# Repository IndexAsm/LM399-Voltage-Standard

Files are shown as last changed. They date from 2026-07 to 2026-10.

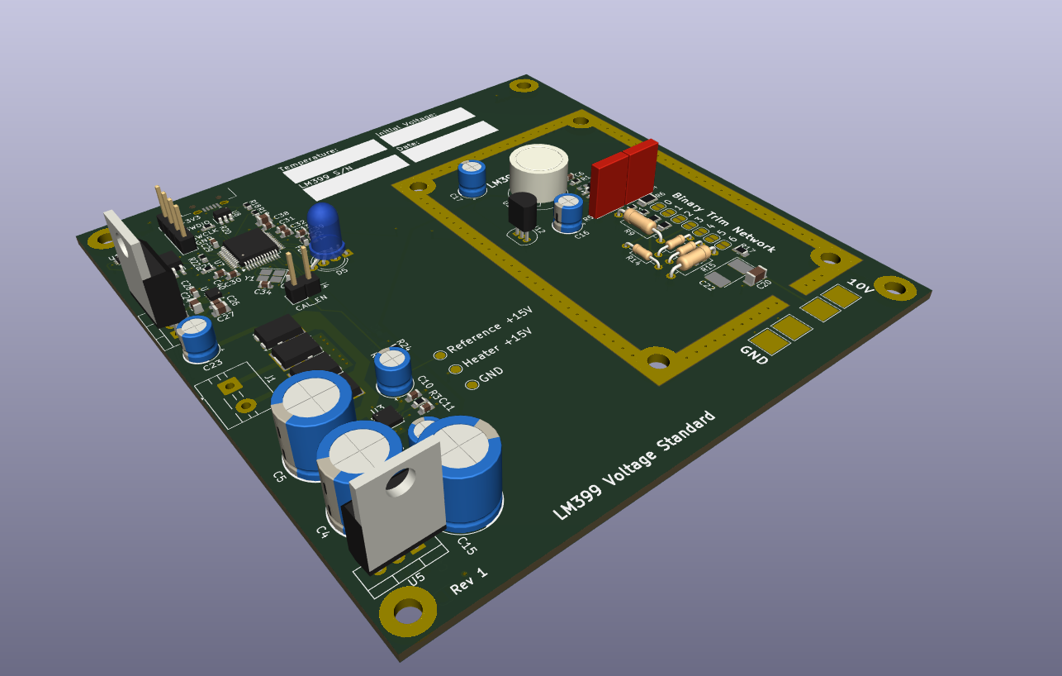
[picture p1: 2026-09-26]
PDF/3D2.png

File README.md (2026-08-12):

# LM399 10V Voltage Standard

10V Voltage Standard used to calibrate equipment.

obraz

## Functions
  - Uptime tracking
  - Temperature tracking
  - Stores calibration data
  - USB connection
  - Status LED
  - Voltage & Current monitoring

## Specifications
  - Calibrated 10 V reference output with ppm-level stability target
  - Low tempco (I am aiming for < 5ppm but that requires testing)
  - Low long term drift ( Also requires testing, in order to determine the value)

## Calibration
  - Short pins on CAL_EN header.
  - Measure the output and adjust the binary trim network accordingly.
  - Connect it to a computer and write changes to eeprom (a special program will be created after constructing the first prototype).
  - Open CAL_EN header.
  - Done!

## Reference
LM399 is chosen as the main reference, which is later amplified to precise 10V with LT1001. It uses precise Z Foil resistors for gain.
It has an internal heater to keep it at stable temperature, in order to prevent output drift.

## PCB
I decided to go with a 4 layer board. This way I can make L2 a solid ground and L3 power. It not only simplifies routing but also improves performance
There is a little space left empty which also has a purpose. This way I can keep digital and power electronics away from sensitive reference part. Voltage regulator can heat up. If they were close to precision section, the trim network would heat up, which would result in output drift.

The reference section has an exposed copper area on the first layer to attach aluminum shielding.

Also there are a few text fields to input measurements, when the device is first calibrated.

obraz

## Software
I used Kicad to design this board.

## [BOM](LM399VoltageStandard.csv)
Total cost: 473,59zł + shipping
That is $127.10 USD
Some parts are left with no price or link. That means I already have them so I did not include them in price calculation.

## Credits
I relied on MarcoReps's videos to learn everything in order to make this project.

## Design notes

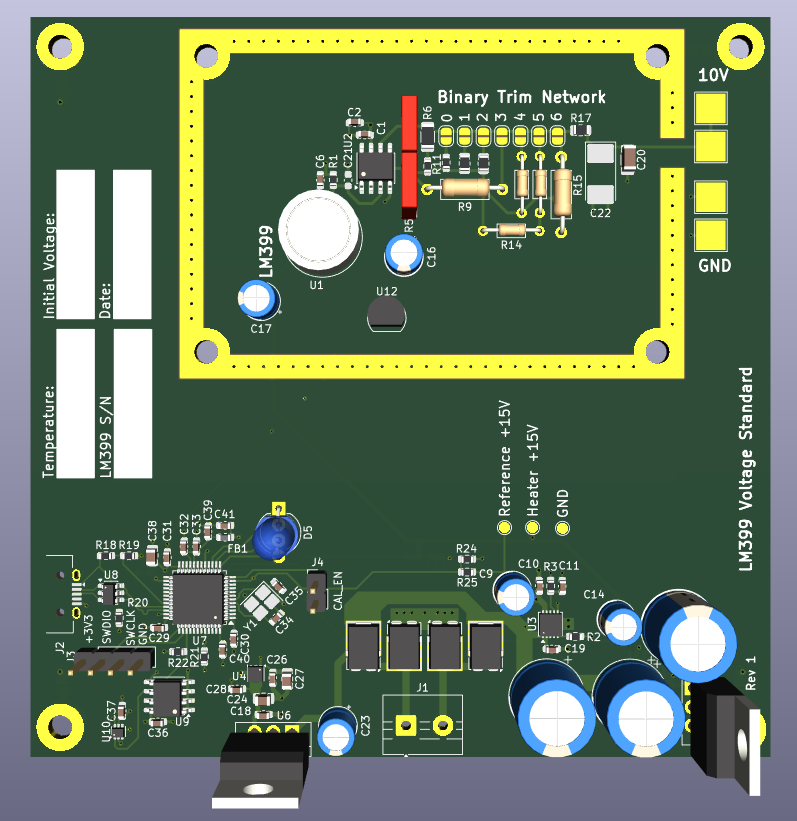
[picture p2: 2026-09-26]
PDF/3D1.png

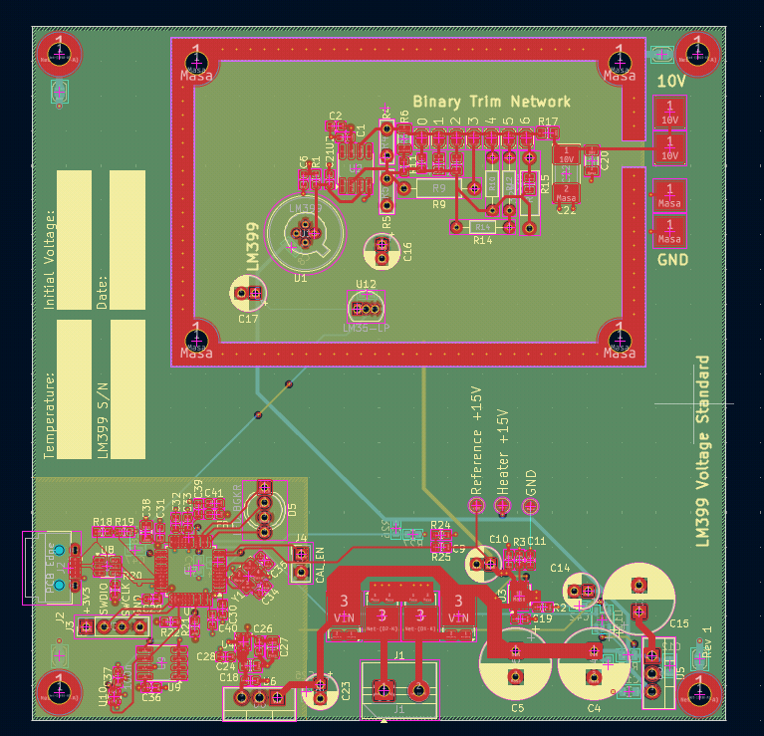
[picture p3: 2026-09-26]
PDF/PCB.png

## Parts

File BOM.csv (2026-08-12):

Reference | Qty | Value | DNP | Price | Link | Footprint
C1,C2,C6,C7,C8,C10,C11,C18,C19,C24,C25,C26,C29,C30,C31,C32,C33,C36,C37,C40,C41,C42,C43,C44,C45,C46,C47 | 27 | 100n |  |  |  | Capacitor_SMD:C_0603_1608Metric
C4,C5,C15 | 3 | 1000u |  |  |  | Capacitor_THT:CP_Radial_D10.0mm_P3.80mm
C9,C14,C16,C17,C23 | 5 | 47u |  |  |  | Capacitor_THT:CP_Radial_D5.0mm_P2.00mm
C12,C13 | 2 | 100n |  |  |  | Capacitor_SMD:C_0805_2012Metric
C20 | 1 | 100n |  | 1,26zł | https://www.mouser.pl/en/ProductDetail/Murata-Electronics/GRM3195C1H104JA05D | Capacitor_SMD:C_1206_3216Metric
C21 | 1 | 1n | DNP |  |  | Capacitor_SMD:C_0603_1608Metric
C22 | 1 | 10u |  |  | https://www.mouser.pl/ProductDetail/KEMET/A700V106M016ATE045?qs=vIXc3t25diAUKxzJ4krppg%3D%3D | Capacitor_Tantalum_SMD:CP_EIA-7132-20_AVX-U
C27,C28,C38 | 3 | 10u |  | 1,51zł | https://www.mouser.pl/en/ProductDetail/Samsung-Electro-Mechanics/CL21A106KOQNNNF | Capacitor_SMD:C_0805_2012Metric
C34,C35 | 2 | 14p |  |  |  | Capacitor_SMD:C_0603_1608Metric
C39 | 1 | 2u2 |  | 0,36zł | https://www.mouser.pl/en/ProductDetail/Samsung-Electro-Mechanics/CL10A225KP8NNNC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 | Capacitor_SMD:C_0603_1608Metric
D1,D2,D3,D4 | 4 | PUUP3JH |  | 15.32zł | https://www.mouser.pl/en/ProductDetail/Taiwan-Semiconductor/PUUP3JH?qs=NeOn4crkEuub6tf3VFnloQ%3D%3D | ""
D5 | 1 | LED_BGKR |  | 0,97zł | https://www.mouser.pl/en/ProductDetail/Soldered/100105?qs=%252BXxaIXUDbq14F%252B3i1Z0hQg%3D%3D | LED_THT:LED_D5.0mm-4_RGB_Wide_Pins
FB1 | 1 | 120R |  | 0,36zł | https://www.mouser.pl/en/ProductDetail/TDK/MMZ1608S121ATA00 | Inductor_SMD:L_0603_1608Metric
J1 | 1 | Screw_Terminal_01x02 |  |  |  | TerminalBlock:TerminalBlock_MaiXu_MX126-5.0-02P_1x02_P5.00mm
J2 | 1 | USB_B_Micro |  |  |  | Connector_USB:USB_Micro-B_Technik_TWP-4002D-H3
J3 | 1 | Conn_01x04 |  |  |  | Connector_PinHeader_2.54mm:PinHeader_1x04_P2.54mm_Vertical
J4 | 1 | Conn_01x02 |  |  |  | Connector_PinHeader_2.54mm:PinHeader_1x02_P2.54mm_Vertical
JP8,JP9,JP10,JP11,JP12,JP13,JP14,JP15,JP16,JP17,JP18 | 11 | Jumper_2_Open |  |  |  | Jumper:SolderJumper-2_P1.3mm_Open_RoundedPad1.0x1.5mm
R1 | 1 | 8k06 |  | 2,71zł | https://www.mouser.pl/ProductDetail/TE-Connectivity-Holsworthy/RN73C1J8K06BTDF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 | Resistor_SMD:R_0603_1608Metric
R2 | 1 | 250 |  |  |  | Resistor_SMD:R_0603_1608Metric
R3 | 1 | 150k |  |  |  | Resistor_SMD:R_0603_1608Metric
R4 | 1 | 5k |  | 141,58zł | https://www.mouser.pl/ProductDetail/Vishay-Precision-Group-Foil-Resistors/Y14535K00000V9L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 | LM399VoltageStandard:ZFoilResistor
R5 | 1 | 10k |  | 104,75zł | https://www.mouser.pl/ProductDetail/Vishay-Precision-Group-Foil-Resistors/Y070610K0000T9L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 | Resistor_THT:R_Axial_DIN0207_L6.3mm_D2.5mm_P10.16mm_Horizontal
R6 | 1 | 2k |  | 9,41zł | https://www.mouser.pl/ProductDetail/SEI-Stackpole/RNCF1206TKW2K00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 | Resistor_SMD:R_1206_3216Metric
R7 | 1 | 1M02 |  | 1,37zł | https://www.mouser.pl/ProductDetail/YAGEO/RT0805BRD071M02L?qs=OLJpxlzHOSSSXA%2FHRgw7Yg%3D%3D | Resistor_SMD:R_0805_2012Metric
R8 | 1 | 2M05 |  | 1,37zł | https://www.mouser.pl/ProductDetail/Kamaya/RGC1-10C2054FTP | Resistor_SMD:R_0805_2012Metric
R9 | 1 | 4M12 |  | 10,67zł | https://www.mouser.pl/ProductDetail/Vishay-Dale/CMF554M1200FHEB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 | Resistor_THT:R_Axial_DIN0207_L6.3mm_D2.5mm_P10.16mm_Horizontal
R10,R12,R14 | 3 | 8M25 |  | 13,70zł | https://www.mouser.pl/ProductDetail/Xicon/270-8.25M-RC?qs=sGAEpiMZZMtlubZbdhIBINFvGMYJRrzyS3Nt80msaes%3D | Resistor_THT:R_Axial_DIN0204_L3.6mm_D1.6mm_P7.62mm_Horizontal
R11 | 1 | 35k7 |  | 3,72zł | https://www.mouser.pl/ProductDetail/TE-Connectivity-Holsworthy/RN73C1J35K7BTDF | Resistor_SMD:R_0603_1608Metric
R13 | 1 | 511k |  | 2,13zł | https://www.mouser.pl/ProductDetail/TE-Connectivity-Holsworthy/RN73C1J511KBTD?qs=CXI0wBT1M2ju4bnzIh8oKg%3D%3D | Resistor_SMD:R_0603_1608Metric
R15 | 1 | 32M |  | 10,67zł | https://www.mouser.pl/ProductDetail/Vishay-Dale/CMF554M1200FHEB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 | Resistor_THT:R_Axial_DIN0207_L6.3mm_D2.5mm_P10.16mm_Horizontal
R16 | 1 | 32M | DNP |  | https://www.mouser.pl/ProductDetail/Kamaya/RGC1-10C2054FTP | Resistor_SMD:R_0805_2012Metric
R17 | 1 | 50R |  | 1,37 | https://www.mouser.pl/ProductDetail/YAGEO/RT0805BRD071M02L?qs=OLJpxlzHOSSSXA%2FHRgw7Yg%3D%3D | Resistor_SMD:R_0805_2012Metric
R18,R19 | 2 | 10k |  |  |  | Resistor_SMD:R_0603_1608Metric
R20 | 1 | 1k5 |  |  |  | Resistor_SMD:R_0603_1608Metric
R21,R22 | 2 | 4k7 |  |  |  | Resistor_SMD:R_0603_1608Metric
R23 | 1 | 0R1 |  | 0,76zł | https://www.mouser.pl/en/ProductDetail/Panasonic/ERJ-6DSJR10V | Resistor_SMD:R_0805_2012Metric
R24,R27 | 2 | 4k |  |  |  | Resistor_SMD:R_0603_1608Metric
R25,R26 | 2 | 20k |  |  |  | Resistor_SMD:R_0603_1608Metric
R28 | 1 | 100R |  |  |  | Resistor_SMD:R_0603_1608Metric
TP2,TP4,TP5 | 3 | TestPoint |  |  |  | TestPoint:TestPoint_Pad_D1.5mm
TP3,TP6,TP7,TP8 | 4 | TestPoint |  |  |  | TestPoint:TestPoint_Pad_4.0x4.0mm
U1 | 1 | LM399 |  |  | https://www.mouser.pl/en/ProductDetail/Analog-Devices/LM399AHPBF?qs=ytflclh7QUUM8sawX7U9qQ%3D%3D | Package_TO_SOT_THT:Analog_TO-46-4_ThermalShield
U2 | 1 | LT1001 |  | 22,51zł | https://www.mouser.pl/ProductDetail/Analog-Devices/LT1001CS8PBF?qs=ytflclh7QUXPrXuaZMy1cA%3D%3D | Package_SO:SOIC-8_3.9x4.9mm_P1.27mm
U3 | 1 | LT3045xDD |  | 33,14zł | https://www.mouser.pl/ProductDetail/Analog-Devices/LT3045EDDPBF?qs=oahfZPh6IAItEW%2FaDCA8LQ%3D%3D | Package_DFN_QFN:DFN-10-1EP_3x3mm_P0.5mm_EP1.65x2.38mm
U4 | 1 | TLV75533PDRV |  | 1,63zł | https://www.mouser.pl/en/ProductDetail/Texas-Instruments/TLV75533PDRVR?qs=lc2O%252BfHJPVbmKlktYGVy6A%3D%3D | Package_SON:WSON-6-1EP_2x2mm_P0.65mm_EP1x1.6mm
U5 | 1 | LM7815 |  |  |  | Package_TO_SOT_THT:TO-220-3_Vertical
U6 | 1 | LM7805_TO220 |  |  |  | Package_TO_SOT_THT:TO-220-3_Vertical
U7 | 1 | STM32G431C6Tx |  | 16,72zł | https://www.mouser.pl/en/ProductDetail/STMicroelectronics/STM32G431C6T6?qs=uwxL4vQweFMIHkXLHKxSFQ%3D%3D | Package_QFP:LQFP-48_7x7mm_P0.5mm
U8 | 1 | USBLC6-2SC6 |  | 1,59zł | https://www.mouser.pl/en/ProductDetail/STMicroelectronics/USBLC6-2SC6?qs=po45yt2pPpu%2FhNIlwQdTlg%3D%3D | Package_TO_SOT_SMD:SOT-23-6
U9 | 1 | FM24C64B |  | 1,12zł | https://www.mouser.pl/en/ProductDetail/STMicroelectronics/M24C64-RMN6TP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 | Package_SO:SOIC-8_3.9x4.9mm_P1.27mm
U10 | 1 | TMP102xxDRL |  | 4,15zł | https://www.mouser.pl/en/ProductDetail/Texas-Instruments/TMP102AQDRLRQ1?qs=asCBFxFfL1SM%2FKfsYcTt1w%3D%3D | Package_TO_SOT_SMD:SOT-563
U11 | 1 | INA180B3 |  | 2,28zł | https://www.mouser.pl/en/ProductDetail/Texas-Instruments/INA180B3QDBVRQ1?qs=l4Gc20tDgJJbJAbKoVt09A%3D%3D | Package_TO_SOT_SMD:SOT-23-5
U12 | 1 | LM35-LP |  |  |  | Package_TO_SOT_THT:TO-92_Inline
Y1 | 1 | Crystal_GND24 |  | 0,87zł | https://www.mouser.pl/en/ProductDetail/Eaton-Electronics/E2X160122X03?qs=%252BXxaIXUDbq2twjo5ayNDpw%3D%3D | Crystal:Crystal_SMD_EuroQuartz_X22-4Pin_2.5x2.0mm_HandSoldering
 | 1 | PCB & shipping
 | 1 | DP-241-4-16 |  | 65,65zł

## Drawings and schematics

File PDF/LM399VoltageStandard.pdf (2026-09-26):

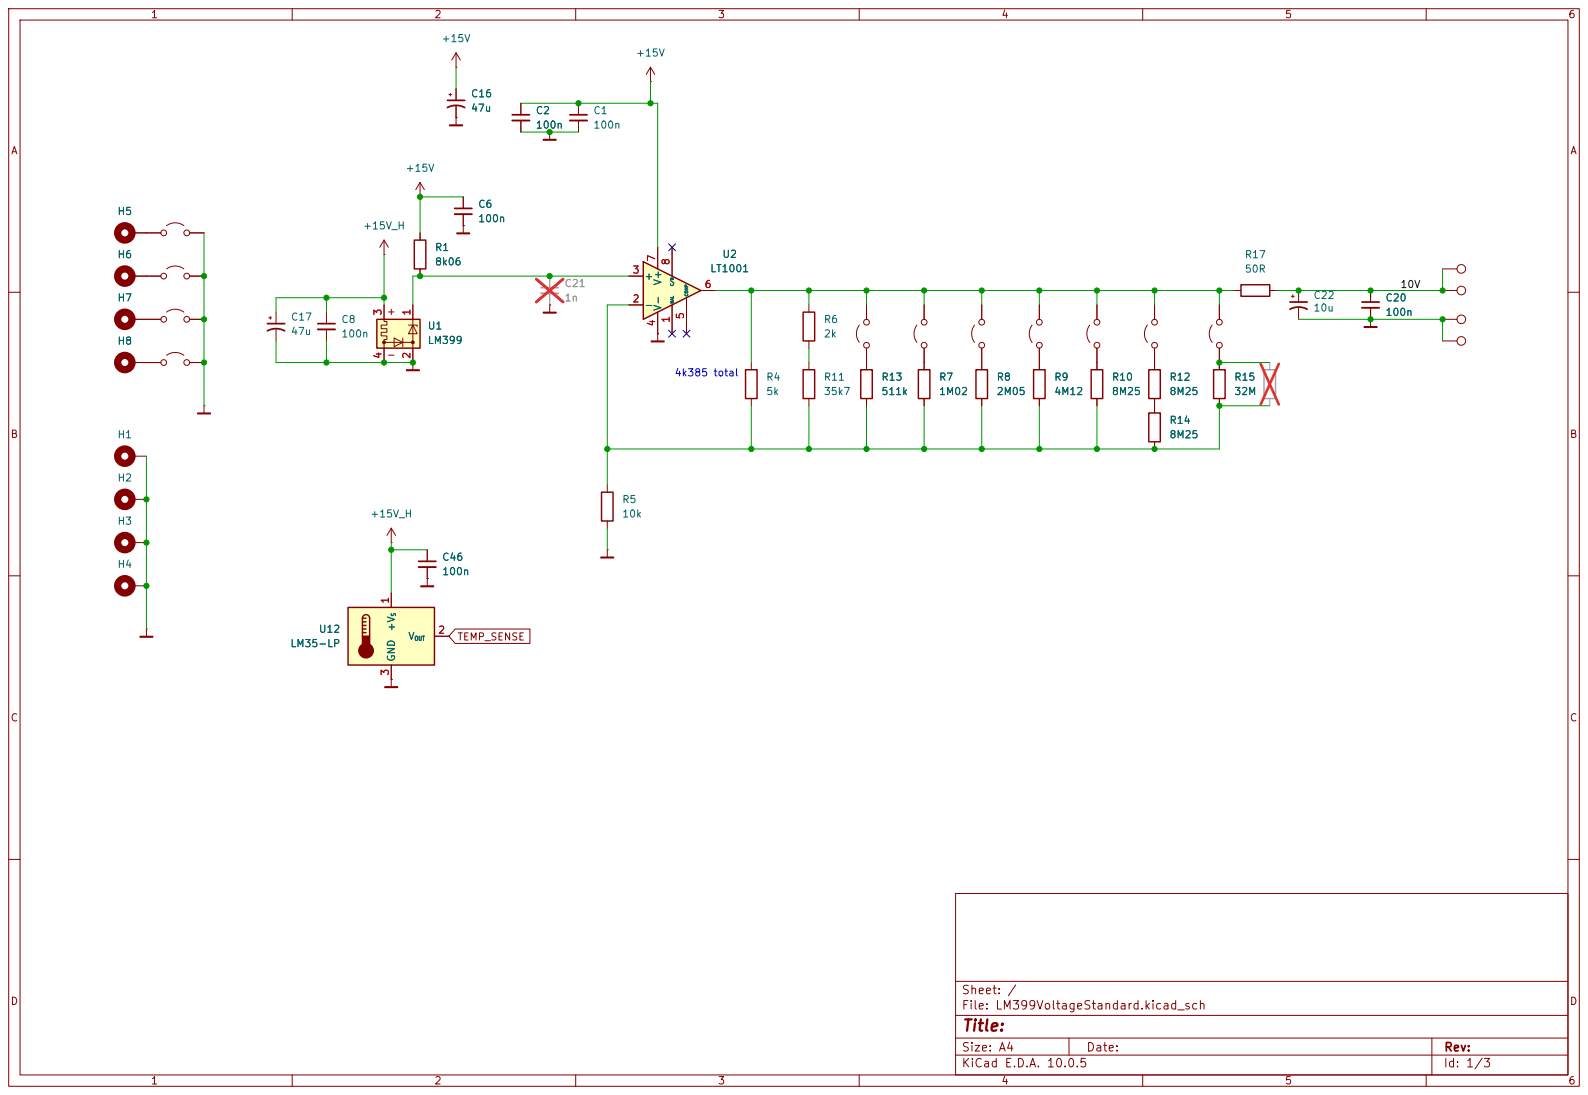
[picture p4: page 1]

Size: A4 | Rev:
KiCad E.D.A. 10.0.5 | Id: 1/3

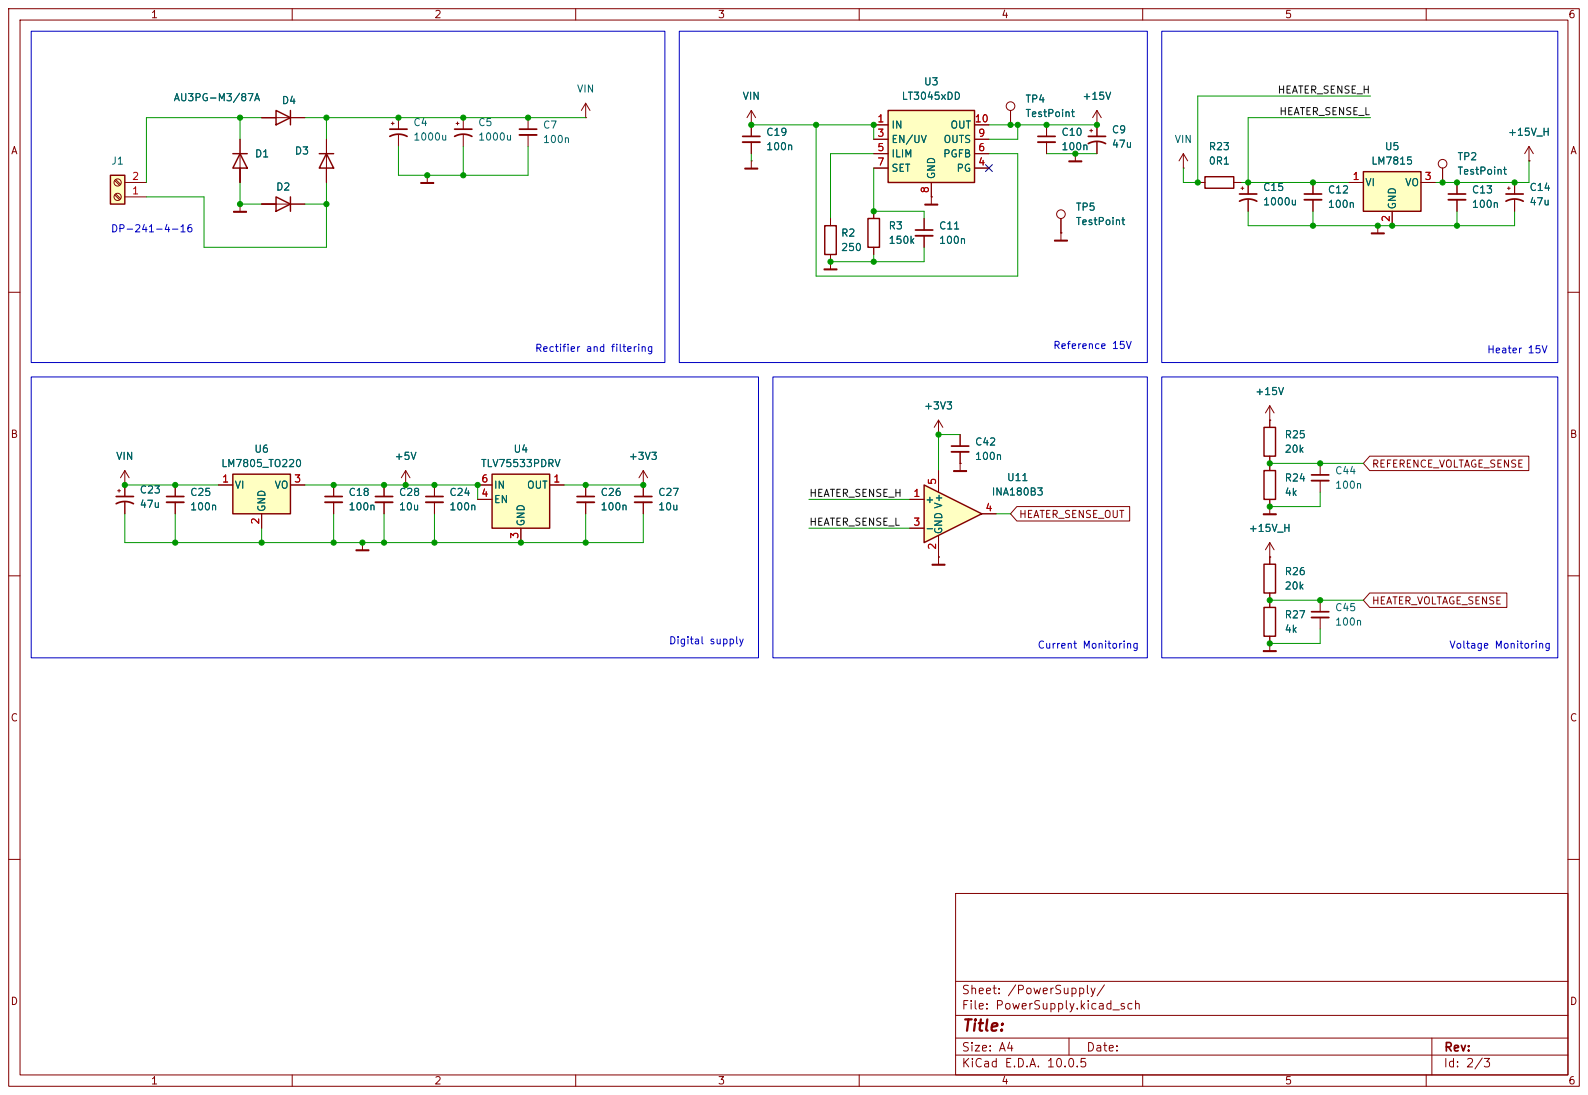
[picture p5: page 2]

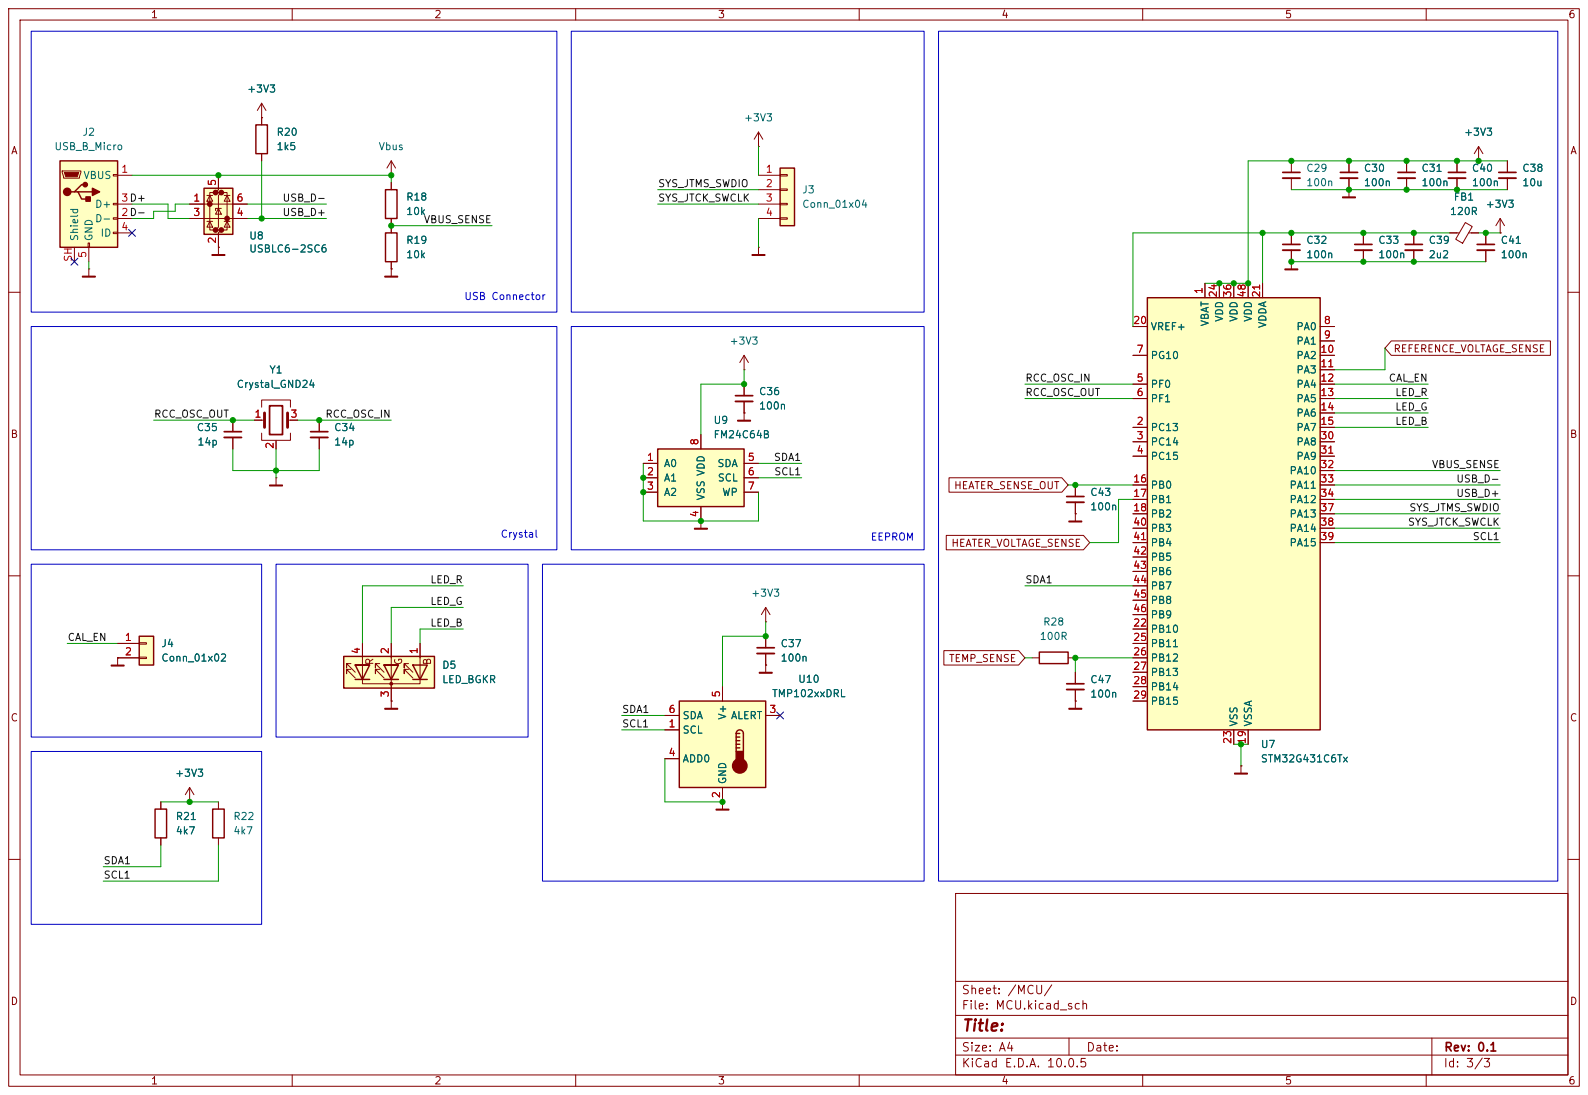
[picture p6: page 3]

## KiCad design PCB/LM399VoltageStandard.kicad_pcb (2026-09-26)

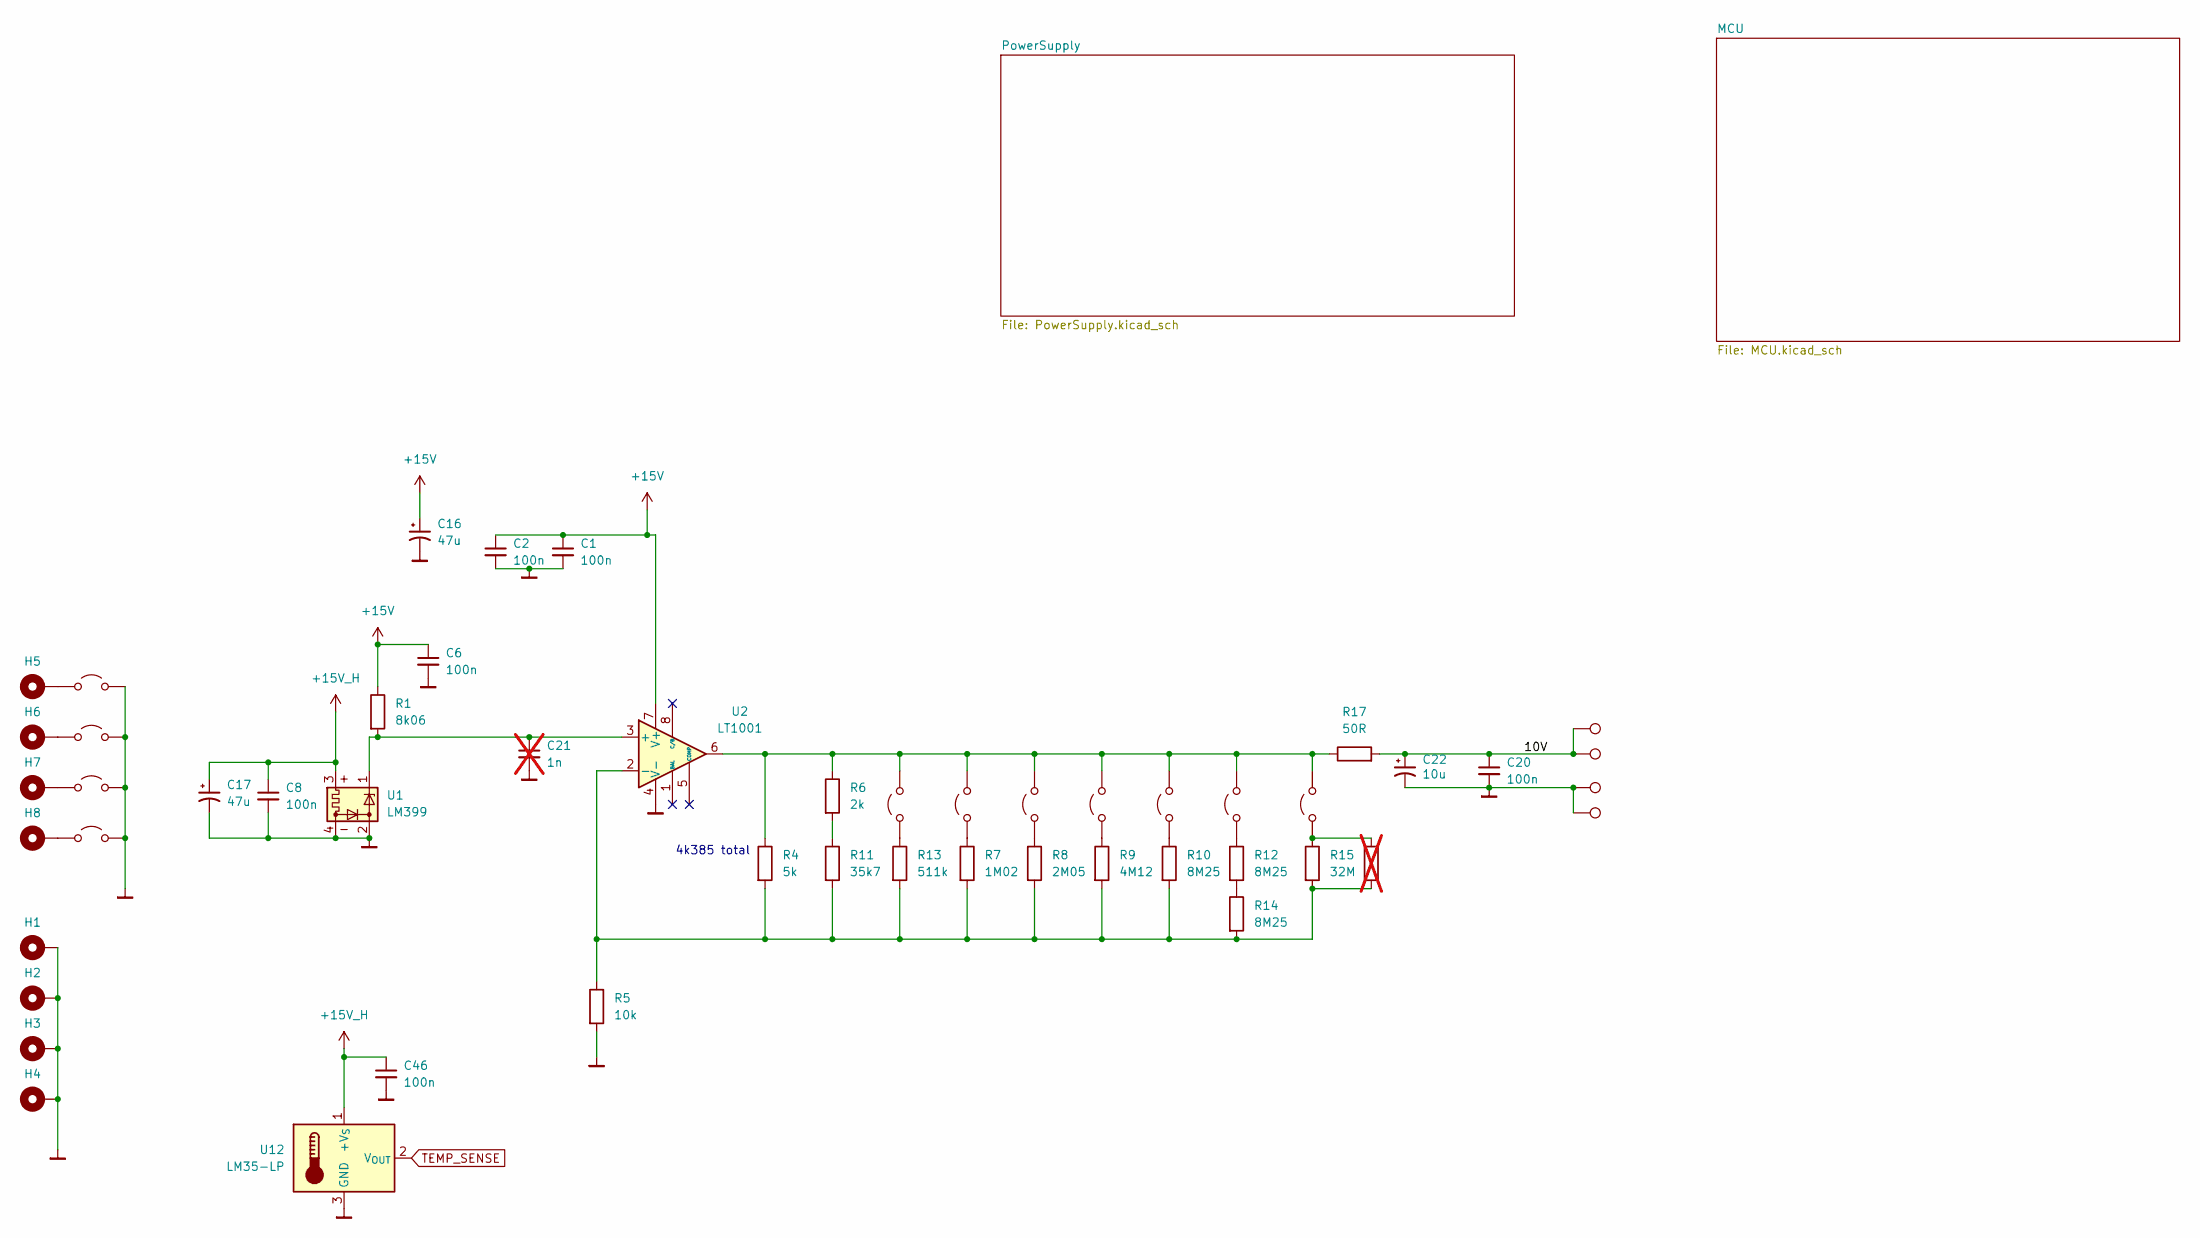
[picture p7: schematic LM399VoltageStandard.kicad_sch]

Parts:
C1, C2, C6, C8, C46: 100n; C_0603_1608Metric
C16, C17: 47u; CP_Radial_D5.0mm_P2.00mm
C20: 100n; C_1206_3216Metric
C21: 1n; C_0603_1608Metric; not fitted
C22: 10u; CP_EIA-7132-20_AVX-U
H1, H2, H3, H4, H5, H6, H7, H8: MountingHole_Pad; MountingHole_3.2mm_M3_Pad_TopBottom
JP8, JP9, JP10, JP11, JP12, JP13, JP14, JP15, JP16, JP17, JP18: Jumper_2_Open; SolderJumper-2_P1.3mm_Open_RoundedPad1.0x1.5mm
R1: 8k06; R_0603_1608Metric
R4: 5k; ZFoilResistor
R5: 10k; R_Axial_DIN0207_L6.3mm_D2.5mm_P10.16mm_Horizontal
R6: 2k; R_1206_3216Metric
R7: 1M02; R_0805_2012Metric
R8: 2M05; R_0805_2012Metric
R9: 4M12; R_Axial_DIN0207_L6.3mm_D2.5mm_P10.16mm_Horizontal
R10, R12, R14: 8M25; R_Axial_DIN0204_L3.6mm_D1.6mm_P7.62mm_Horizontal
R11: 35k7; R_0603_1608Metric
R13: 511k; R_0603_1608Metric
R15: 32M; R_Axial_DIN0207_L6.3mm_D2.5mm_P10.16mm_Horizontal
R16: 32M; R_0805_2012Metric; not fitted
R17: 50R; R_0805_2012Metric
TP3, TP6, TP7, TP8: TestPoint; TestPoint_Pad_4.0x4.0mm
U1: LM399; Analog_TO-46-4_ThermalShield
U2: LT1001; SOIC-8_3.9x4.9mm_P1.27mm
U12: LM35-LP; TO-92_Inline

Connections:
+15V: C1.1, C2.1, C6.1, C16.1, R1.1, U2.7 (V+); also elsewhere on the board
+15V_H: C8.1, C17.1, C46.1, U1.3, U12.1 (+V_{S}); also elsewhere on the board
/10V: C20.1, C22.1, R17.2, TP3.1 (1_1), TP7.1 (1_1)
Masa: C1.2, C2.2, C6.2, C8.2, C16.2, C17.2, C20.2, C21.2, C22.2, C46.2, H1.1 (1_1), H2.1 (1_1), H3.1 (1_1), H4.1 (1_1), JP15.2 (B), JP16.2 (B), JP17.2 (B), JP18.2 (B), R5.2, TP6.1 (1_1), TP8.1 (1_1), U1.2, U1.4, U2.4 (V-), U12.3 (GND); also elsewhere on the board
unnamed: JP8.1 (A), R13.1
unnamed: JP9.1 (A), R7.1
unnamed: JP10.1 (A), R8.1
unnamed: JP8.2 (B), JP9.2 (B), JP10.2 (B), JP11.2 (B), JP12.2 (B), JP13.2 (B), JP14.2 (B), R4.1, R6.1, R17.1, U2.6
unnamed: JP11.1 (A), R9.1
unnamed: JP12.1 (A), R10.1
unnamed: JP13.1 (A), R12.1
unnamed: JP14.1 (A), R15.1, R16.1
unnamed: H5.1 (1_1), JP15.1 (A)
unnamed: H6.1 (1_1), JP16.1 (A)
unnamed: H7.1 (1_1), JP17.1 (A)
unnamed: H8.1 (1_1), JP18.1 (A)
unnamed: R6.2, R11.1
unnamed: R12.2, R14.1
unnamed: C21.1, R1.2, U1.1, U2.3 (+)
unnamed: R4.2, R5.1, R7.2, R8.2, R9.2, R10.2, R11.2, R13.2, R14.2, R15.2, R16.2, U2.2 (-)
TEMP_SENSE: U12.2 (V_{OUT}); also elsewhere on the board

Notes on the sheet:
4k385 total

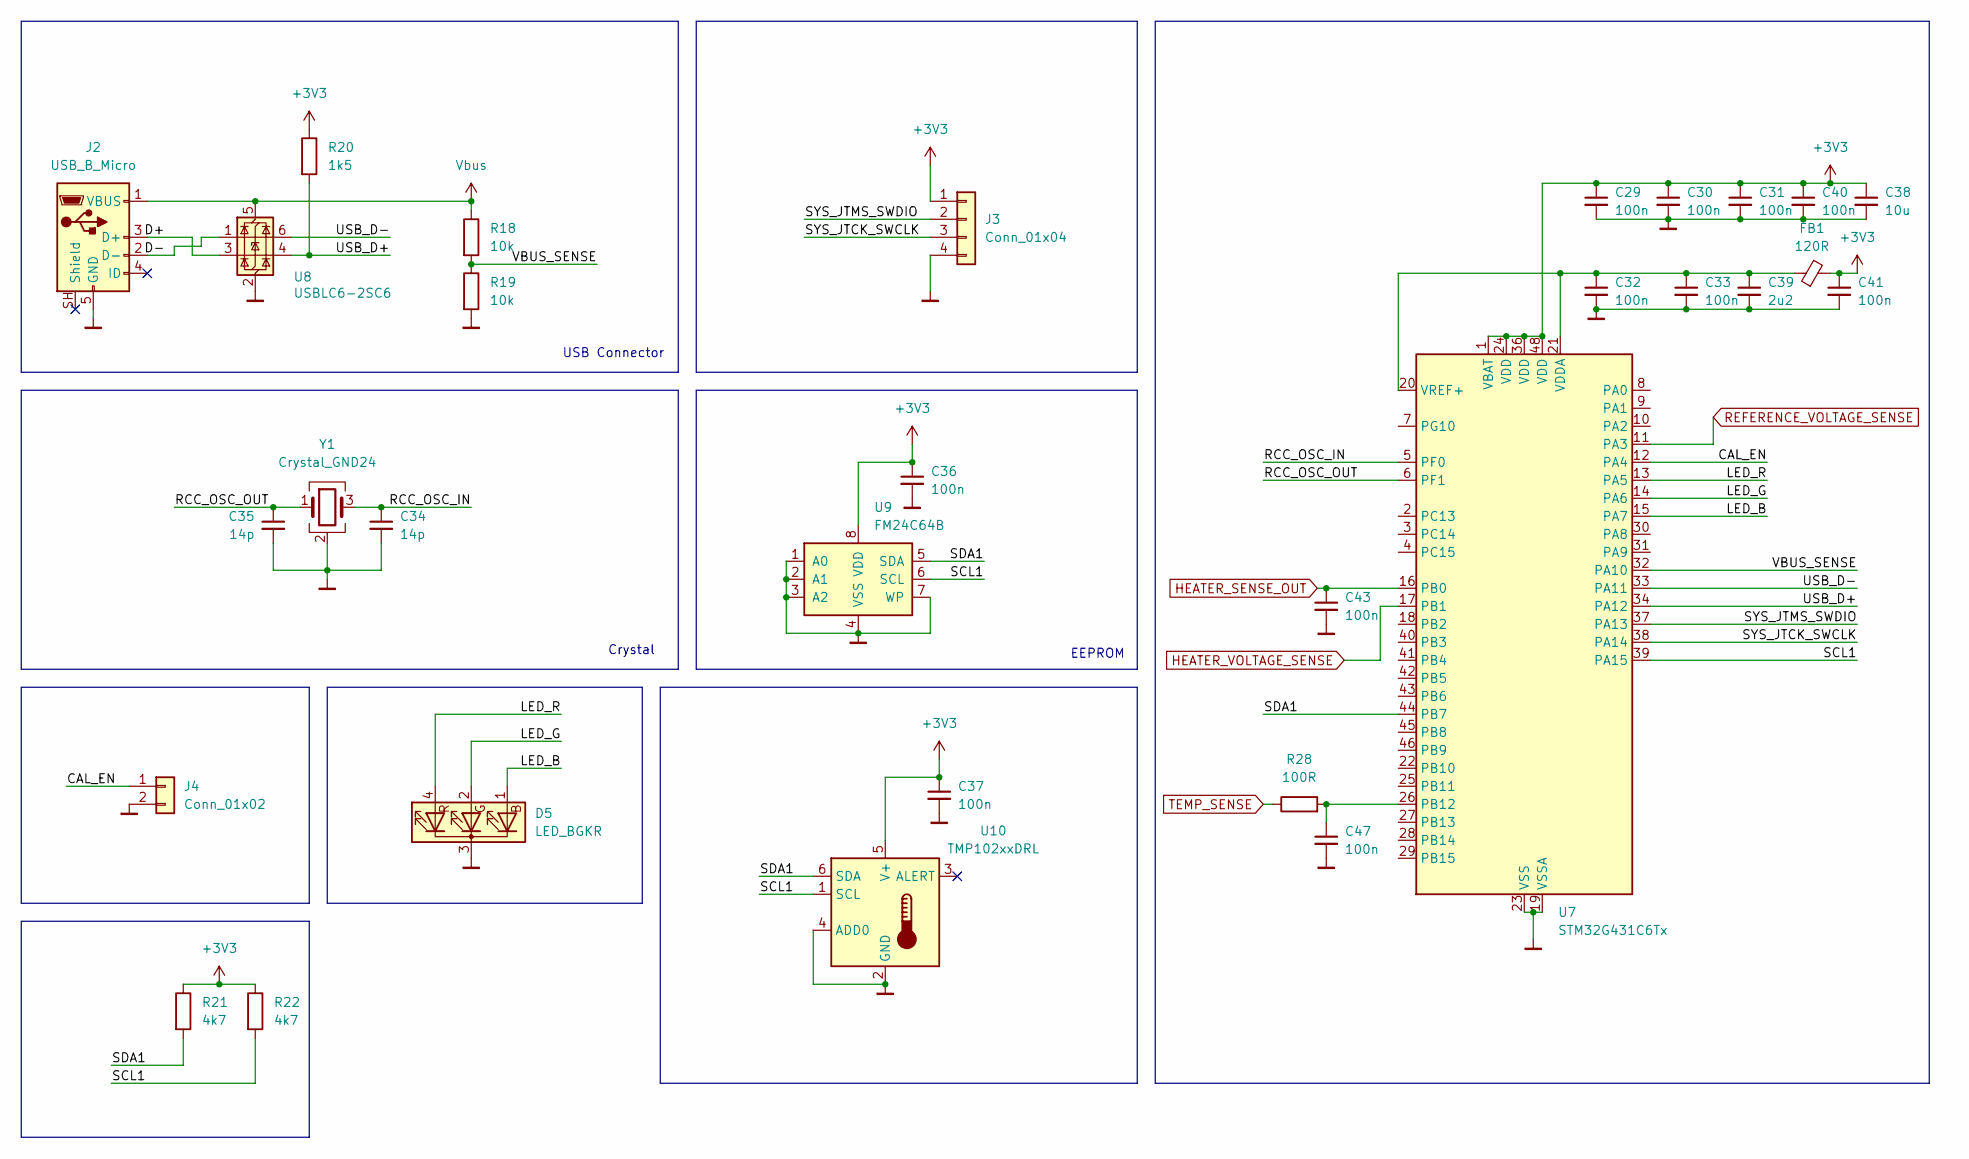
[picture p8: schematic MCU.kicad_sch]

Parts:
C29, C30, C31, C32, C33, C36, C37, C40, C41, C43, C47: 100n; C_0603_1608Metric
C34, C35: 14p; C_0603_1608Metric
C38: 10u; C_0805_2012Metric
C39: 2u2; C_0603_1608Metric
D5: LED_BGKR; LED_D5.0mm-4_RGB_Wide_Pins
FB1: 120R; L_0603_1608Metric
J2: USB_B_Micro; USB_Micro-B_Technik_TWP-4002D-H3
J3: Conn_01x04; PinHeader_1x04_P2.54mm_Vertical
J4: Conn_01x02; PinHeader_1x02_P2.54mm_Vertical
R18, R19: 10k; R_0603_1608Metric
R20: 1k5; R_0603_1608Metric
R21, R22: 4k7; R_0603_1608Metric
R28: 100R; R_0603_1608Metric
U7: STM32G431C6Tx; LQFP-48_7x7mm_P0.5mm
U8: USBLC6-2SC6; SOT-23-6
U9: FM24C64B; SOIC-8_3.9x4.9mm_P1.27mm
U10: TMP102xxDRL; SOT-563
Y1: Crystal_GND24; Crystal_SMD_EuroQuartz_X22-4Pin_2.5x2.0mm_HandSoldering

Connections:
+3V3: C29.1, C30.1, C31.1, C36.1, C37.1, C38.1, C40.1, C41.1, FB1.2, J3.1, R20.1, R21.1, R22.1, U7.1 (VBAT), U7.24 (VDD), U7.36 (VDD), U7.48 (VDD), U9.8 (VDD), U10.5 (V+); also elsewhere on the board
/MCU/CAL_EN: J4.1, U7.12 (PA4)
/MCU/D+: J2.3 (D+), U8.3 (I/O2)
/MCU/D-: J2.2 (D-), U8.1 (I/O1)
/MCU/LED_B: D5.1 (BA), U7.15 (PA7)
/MCU/LED_G: D5.2 (GA), U7.14 (PA6)
/MCU/LED_R: D5.4 (RA), U7.13 (PA5)
/MCU/RCC_OSC_IN: C34.1, U7.5 (PF0), Y1.3
/MCU/RCC_OSC_OUT: C35.1, U7.6 (PF1), Y1.1
/MCU/SCL1: R22.2, U7.39 (PA15), U9.6 (SCL), U10.1 (SCL)
/MCU/SDA1: R21.2, U7.44 (PB7), U9.5 (SDA), U10.6 (SDA)
/MCU/SYS_JTCK_SWCLK: J3.3, U7.38 (PA14)
/MCU/SYS_JTMS_SWDIO: J3.2, U7.37 (PA13)
/MCU/USB_D+: R20.2, U7.34 (PA12), U8.4 (I/O2)
/MCU/USB_D-: U7.33 (PA11), U8.6 (I/O1)
/MCU/VBUS_SENSE: R18.2, R19.1, U7.32 (PA10)
HEATER_SENSE_OUT: C43.1, U7.16 (PB0); also elsewhere on the board
HEATER_VOLTAGE_SENSE: U7.17 (PB1); also elsewhere on the board
Masa: C29.2, C30.2, C31.2, C32.2, C33.2, C34.2, C35.2, C36.2, C37.2, C38.2, C39.2, C40.2, C41.2, C43.2, C47.2, D5.3 (K), J2.5 (GND), J3.4, J4.2, R19.2, U7.19 (VSSA), U7.23 (VSS), U7.35 (VSS), U7.47 (VSS), U8.2 (GND), U9.1 (A0), U9.2 (A1), U9.3 (A2), U9.4 (VSS), U9.7 (WP), U10.2 (GND), U10.4 (ADD0), Y1.2 (G), Y1.4 (G); also elsewhere on the board
unnamed: C47.1, R28.2, U7.26 (PB12)
unnamed: C32.1, C33.1, C39.1, FB1.1, U7.20 (VREF+), U7.21 (VDDA)
REFERENCE_VOLTAGE_SENSE: U7.11 (PA3); also elsewhere on the board
TEMP_SENSE: R28.1; also elsewhere on the board
Vbus: J2.1 (VBUS), R18.1, U8.5 (VBUS)

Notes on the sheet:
Crystal
EEPROM
USB Connector

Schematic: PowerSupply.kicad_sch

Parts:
C4, C5, C48: 1000u; CP_Radial_D10.0mm_P3.80mm
C7, C10, C18, C19, C24, C25, C26, C42, C44, C45: 100n; C_0603_1608Metric
C9, C14, C23: 47u; CP_Radial_D5.0mm_P2.00mm
C12, C13: 100n; C_0805_2012Metric
C15: PUUP3JH; CP_Radial_D10.0mm_P3.80mm
C27, C28: 10u; C_0805_2012Metric
D2, D3, D4: PUUP3JH; TO-277A
D6: B40C2300-1500A; Diode_Bridge_19.0x3.5x10.0mm_P5.0mm
J1: Screw_Terminal_01x02; TerminalBlock_MaiXu_MX126-5.0-02P_1x02_P5.00mm
R23: 0R1; R_0805_2012Metric
R24, R27: 4k; R_0603_1608Metric
R25, R26: 20k; R_0603_1608Metric
TP2, TP4, TP5: TestPoint; TestPoint_Pad_D1.5mm
U4: TLV75533PDRV; WSON-6-1EP_2x2mm_P0.65mm_EP1x1.6mm
U5, U13: LM7815; TO-220-3_Vertical
U6: LM7805_TO220; TO-220-3_Vertical
U11: INA180B3; SOT-23-5

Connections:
+3V3: C26.1, C27.1, C42.1, U4.1 (OUT), U11.5 (V+); also elsewhere on the board
+5V: C18.1, C24.1, C28.1, U4.4 (EN), U4.6 (IN), U6.3 (VO)
+15V: C9.1, C10.1, R25.1, TP4.1 (1_1), U13.3 (VO); also elsewhere on the board
+15V_H: C13.1, C14.1, R26.1, TP2.1 (1_1), U5.3 (VO); also elsewhere on the board
/PowerSupply/HEATER_SENSE_L: C12.1, C15.1, R23.2, U5.1 (VI), U11.3 (-)
HEATER_SENSE_OUT: U11.4; also elsewhere on the board
HEATER_VOLTAGE_SENSE: C45.1, R26.2, R27.1; also elsewhere on the board
Masa: C4.2, C5.2, C7.2, C9.2, C10.2, C12.2, C13.2, C14.2, C15.2, C18.2, C19.2, C23.2, C24.2, C25.2, C26.2, C27.2, C28.2, C42.2, C44.2, C45.2, C48.2, D6.1 (-), R24.2, R27.2, TP5.1 (1_1), U4.3 (GND), U4.7 (GND), U5.2 (GND), U6.2 (GND), U11.2 (GND), U13.2 (GND); also elsewhere on the board
unnamed: D6.3, J1.1
unnamed: D6.2, J1.2
REFERENCE_VOLTAGE_SENSE: C44.1, R24.1, R25.2; also elsewhere on the board
VIN: C4.1, C5.1, C7.1, C19.1, C23.1, C25.1, C48.1, D6.4 (+), R23.1, U6.1 (VI), U11.1 (+), U13.1 (VI)

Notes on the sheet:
DP-241-4-16
Voltage Monitoring
Rectifier and filtering
Current Monitoring
Digital supply
Reference 15V
Heater 15V

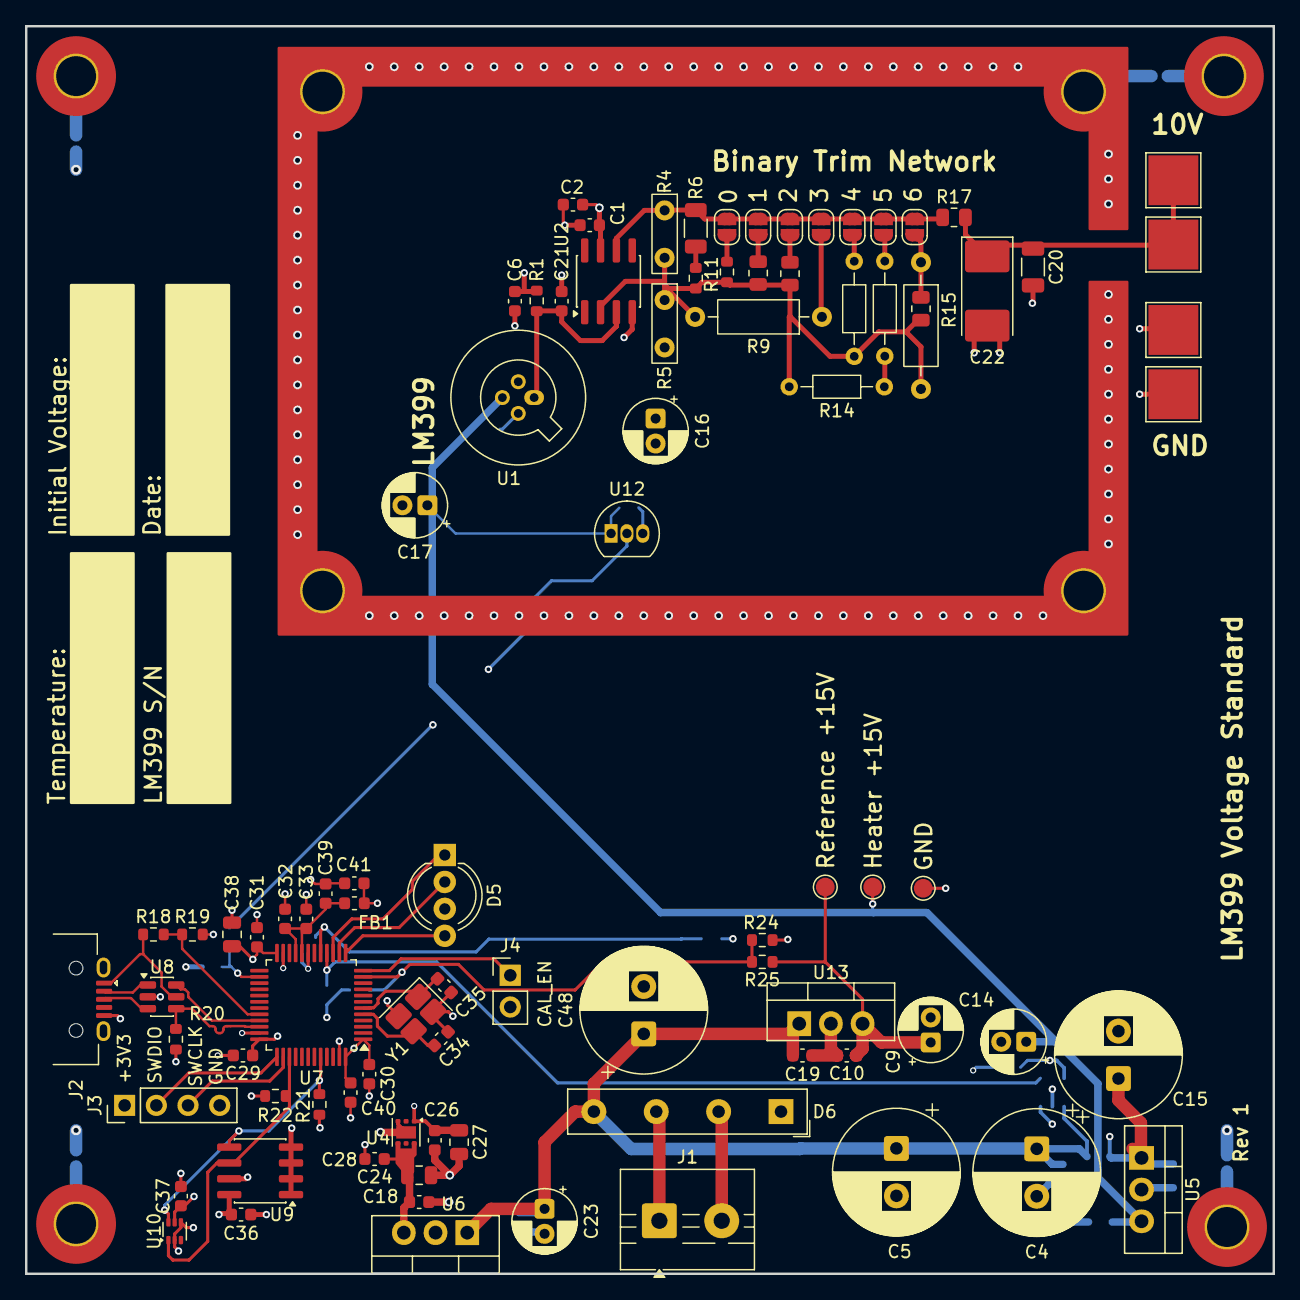
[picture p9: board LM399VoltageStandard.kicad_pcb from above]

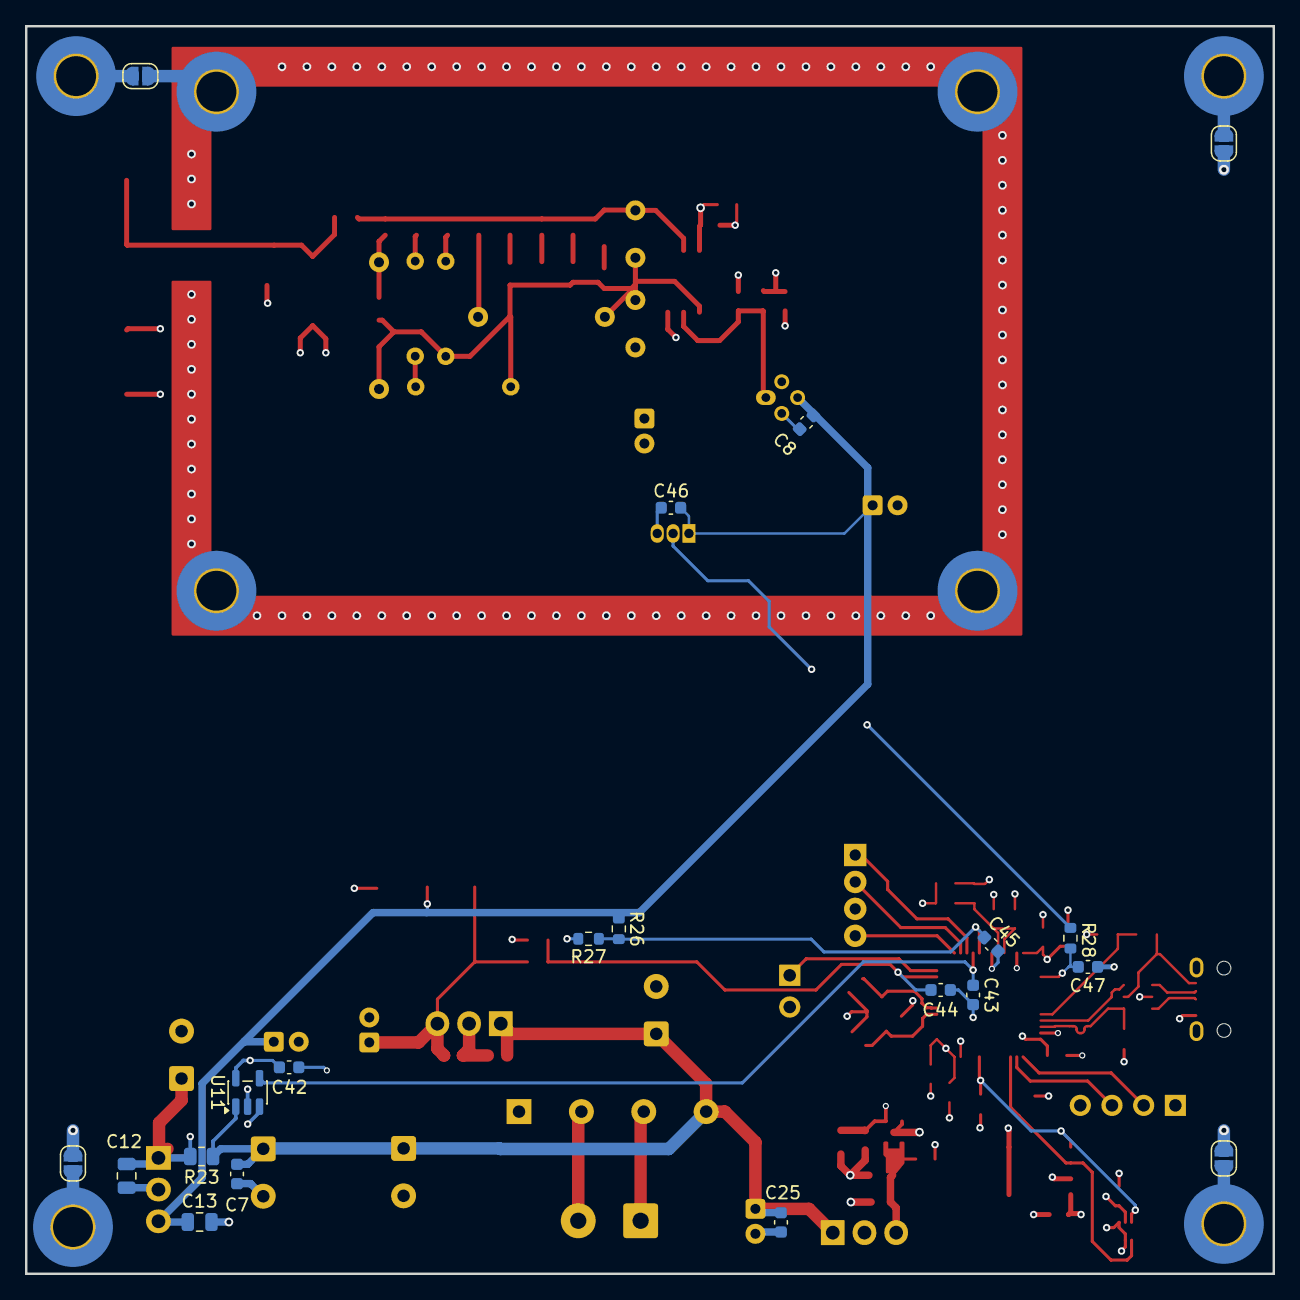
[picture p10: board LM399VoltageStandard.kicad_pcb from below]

Board: 4 copper layers, 100.0 x 100.0 mm, 118 parts (20 on the bottom side), 48 nets.

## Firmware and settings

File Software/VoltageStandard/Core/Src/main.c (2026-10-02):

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
/* Includes ------------------------------------------------------------------*/
#include "main.h"
#include "usb_device.h"

/* USER CODE BEGIN Includes */
#include <stm32g431xx.h>
#include <stm32g4xx_hal_pwr_ex.h>
#include <stm32g4xx_hal_pcd.h>
#include <stm32g4xx_hal_rcc.h>
#include <stm32_hal_legacy.h>
#include "usbd_cdc_if.h"
#include <TMP102.h>
#include <M24Cxx.h>
#include <CalibrationData.h>
/* USER CODE END Includes */

/* USER CODE BEGIN PD */
#define USB_BUFLEN 128


#define EEPROM_SIZE_KB 8

#define EEPROM_ADDR_INIT_CAL_DONE 0x1
#define EEPROM_ADDR_OPERATING_TIME 0x2
#define EEPROM_ADDR_CAL_DATA_STRUC 0xf


/* USER CODE END PD */

ADC_HandleTypeDef hadc1;

I2C_HandleTypeDef hi2c1;

TIM_HandleTypeDef htim16;

/* USER CODE BEGIN PV */
uint8_t usbTxBuffer[USB_BUFLEN];
uint16_t usbTxBufferLen;
/* USER CODE END PV */

void SystemClock_Config(void);
static void MX_GPIO_Init(void);
static void MX_ADC1_Init(void);
static void MX_I2C1_Init(void);
static void MX_TIM16_Init(void);
/* USER CODE BEGIN 0 */

uint16_t ReadHourStats(M24Cxx* eeprom) {
    union HourBuffer {
        uint8_t b8[2];
        uint16_t b16;
    }  buffer;

    M24Cxx_Read_Bytes(eeprom, EEPROM_ADDR_OPERATING_TIME, buffer.b8, 2);
    return buffer.b16;
}

void WriteHourStats(M24Cxx* eeprom, uint16_t val) {
    union HourBuffer {
        uint8_t b8[2];
        uint16_t b16;
    }  buffer;

    buffer.b16 = val;

    M24Cxx_Write_Buffer(eeprom, EEPROM_ADDR_OPERATING_TIME, buffer.b8, 2);
}


void WriteInitialCalibration(
    M24Cxx* eeprom, 
    const char* LM399_serial_number, 
    const char* initial_cal_date,
    const char* initial_cal_voltage,
    float initial_cal_temperature
) {

    if (M24Cxx_Read_Byte(eeprom, EEPROM_ADDR_INIT_CAL_DONE))
        return;
    CalibrationDataInfo calInfo;
    calInfo.entry_addr = 0x20 + sizeof(CalibrationDataInfo);
    calInfo.entry_size = 0xf;
    calInfo.len = 0;
    strcpy(calInfo.LM399_serial_number, LM399_serial_number);
    strcpy(calInfo.initial_cal_date, initial_cal_date);
    strcpy(calInfo.initial_cal_voltage, initial_cal_voltage);
    calInfo.initial_cal_temperature = initial_cal_temperature;
    M24Cxx_Write_Buffer(eeprom, EEPROM_ADDR_OPERATING_TIME, (uint8_t*)&calInfo, sizeof(CalibrationDataInfo));

    M24Cxx_Write_Byte(&eeprom, EEPROM_ADDR_INIT_CAL_DONE, 1);
}

/* USER CODE END 0 */

/**
  * @brief  The application entry point.
  * @retval int
  */
int main(void)
{

  /* MCU Configuration--------------------------------------------------------*/

  /* Reset of all peripherals, Initializes the Flash interface and the Systick. */
  HAL_Init();

  /* Configure the system clock */
  SystemClock_Config();

  /* Initialize all configured peripherals */
  MX_GPIO_Init();
  MX_ADC1_Init();
  MX_I2C1_Init();
  MX_TIM16_Init();
  MX_USB_Device_Init();
  /* USER CODE BEGIN 2 */

    // Debug
    #define HEATUP_TIME 2000
    // Final
    //#define HEATUP_TIME 600000


    uint32_t time_setup_start = HAL_GetTick();
    uint8_t heater_state = 0;

    HAL_GPIO_WritePin(LED_R_GPIO_Port, LED_R_Pin, 1);


    // Setup timer

    HAL_TIM_Base_Start(&htim16);
    uint32_t uptime_start = HAL_GetTick();
    uint32_t uptime_s = 0;

    M24Cxx eeprom = M24Cxx_Init(
        &hi2c1, 
        0b1010000, 
        8, 
        32, 
        I2C_MEMADD_SIZE_16BIT
    );

    uint16_t uptime_h = ReadHourStats(&eeprom);





    HAL_Delay(2000);


  /* USER CODE END 2 */

  /* Infinite loop */
  /* USER CODE BEGIN WHILE */
    while (1)
    {
        if (!heater_state) {
            if (HAL_GetTick() - time_setup_start > HEATUP_TIME) {
                heater_state = 1;
                HAL_GPIO_WritePin(LED_R_GPIO_Port, LED_R_Pin, 0);
                HAL_GPIO_WritePin(LED_G_GPIO_Port, LED_G_Pin, 1);
            }
        }

        


        // Get counter value
        uint32_t uptime = HAL_GetTick();
        if (uptime - uptime_start > 1000) {
            uptime_start = uptime;
            uptime_s++;
            if (uptime_s >= 3600) {
                uptime_s = 0;
                uptime_h++;
                WriteHourStats(&eeprom, uptime_h);
            }
            usbTxBufferLen = snprintf((char*)usbTxBuffer, USB_BUFLEN, "Uptime: %uh %us\r\n",uptime_h, uptime_s);
            while(CDC_Transmit_FS(usbTxBuffer, usbTxBufferLen) == USBD_BUSY) {}


            float temp = TMP102_GetReading(&hi2c1);
            uint32_t integer_part = (int)temp;                             // 12
            uint32_t fractional_part = (int)((temp - integer_part) * 100);
            usbTxBufferLen = snprintf((char*)usbTxBuffer, USB_BUFLEN, "Temperature: %lu.%lu°C\r\n", integer_part, fractional_part);
            while(CDC_Transmit_FS(usbTxBuffer, usbTxBufferLen) == USBD_BUSY) {}

            uint8_t byte_res = M24Cxx_Read_Byte(&eeprom, 0x0);

            usbTxBufferLen = snprintf((char*)usbTxBuffer, USB_BUFLEN, "EEPROM: %u\r\n", (uint16_t) byte_res);
            while(CDC_Transmit_FS(usbTxBuffer, usbTxBufferLen) == USBD_BUSY) {}
        }


    /* USER CODE END WHILE */

    /* USER CODE BEGIN 3 */
    }
  /* USER CODE END 3 */
}

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


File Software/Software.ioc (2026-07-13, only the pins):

Mcu.UserName=STM32G431C6Tx
PA10.Signal=GPIO_Input
PA11.Signal=USB_DM
PA12.Signal=USB_DP
PA13.Signal=SYS_JTMS-SWDIO
PA14.Signal=SYS_JTCK-SWCLK
PA15.Signal=I2C1_SCL
PA3.GPIO_Label=REFERENCE_VOLTAGE_SENSE
PA3.Signal=ADC1_IN4
PA4.GPIO_Label=CAL_EN
PA4.Signal=GPIO_Output
PA5.GPIO_Label=LED_R
PA5.Signal=GPIO_Output
PA6.GPIO_Label=LED_G
PA6.Signal=GPIO_Output
PA7.GPIO_Label=LED_B
PA7.Signal=GPIO_Output
PB0.GPIO_Label=HEATER_CURRENT_SENSE
PB0.Signal=ADC1_IN15
PB1.GPIO_Label=HEATER_VOLTAGE_SENSE
PB1.Signal=ADC1_IN12
PB12.GPIO_Label=TEMP_SENSE
PB12.Signal=ADC1_IN11
PB7.Signal=I2C1_SDA
PF0-OSC_IN.Signal=RCC_OSC_IN
PF1-OSC_OUT.Signal=RCC_OSC_OUT

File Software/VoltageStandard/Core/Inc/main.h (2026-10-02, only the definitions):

#define CAL_EN_Pin GPIO_PIN_4
#define CAL_EN_GPIO_Port GPIOA
#define LED_R_Pin GPIO_PIN_5
#define LED_R_GPIO_Port GPIOA
#define LED_G_Pin GPIO_PIN_6
#define LED_G_GPIO_Port GPIOA
#define LED_B_Pin GPIO_PIN_7
#define LED_B_GPIO_Port GPIOA
#define HEATER_I_SENSE_Pin GPIO_PIN_0
#define HEATER_I_SENSE_GPIO_Port GPIOB
#define HEATER_V_SENSE_Pin GPIO_PIN_1
#define HEATER_V_SENSE_GPIO_Port GPIOB
#define TEMP_SENSE_Pin GPIO_PIN_12
#define TEMP_SENSE_GPIO_Port GPIOB
#define VBUS_SENSE_Pin GPIO_PIN_10
#define VBUS_SENSE_GPIO_Port GPIOA

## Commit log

2026-07-09 Add initial README for LM399 Voltage Standard project
2026-07-09 Power Supply
    [LM399VoltageStandard.kicad_pcb, LM399VoltageStandard.kicad_sch]
2026-07-10 Started PCB
    [LM399VoltageStandard.kicad_pcb, LM399VoltageStandard.kicad_sch]
2026-07-11 Added MCU
    [LM399VoltageStandard.kicad_pcb, MCU.kicad_sch, PowerSupply.kicad_sch]
2026-07-13 Final Version
    [LM399VoltageStandard.kicad_pcb, LM399VoltageStandard.kicad_sch, MCU.kicad_sch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]
2026-07-13 Add software section to README
    Added a section about the software used for board design.
2026-07-13 Add calibration instructions to README
    Added calibration section with adjustment instructions.
2026-07-13 Update README with corrections and additional images
    Corrected the tempco specification from '< 5pp' to '< 5ppm' and added calibration steps for the CAL_EN header. Included additional images for reference.
2026-07-13 Clarify voltage output specification in README
    Updated the specifications section to clarify the voltage output description.
2026-07-13 Silkscreen fix
    [LM399VoltageStandard.kicad_pcb]
2026-07-13 Added BOM
    [LM399VoltageStandard.csv, LM399VoltageStandard.kicad_pcb, MCU.kicad_sch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]
2026-08-12 Changed Diodes in rectifier
    [PowerSupply.kicad_sch]
2026-08-12 Renamed BOM to BOM.csv
    [BOM.csv]
2026-09-26 File Sorting
    [LM399VoltageStandard.kicad_pcb, LM399VoltageStandard.kicad_sch, MCU.kicad_sch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]
2026-10-02 Improved EEPROM lib and added hour uptime tracking and function for initial calibration
2026-10-28 fixed BOM

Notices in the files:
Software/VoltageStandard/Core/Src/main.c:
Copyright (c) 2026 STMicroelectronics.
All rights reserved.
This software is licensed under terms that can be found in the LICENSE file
